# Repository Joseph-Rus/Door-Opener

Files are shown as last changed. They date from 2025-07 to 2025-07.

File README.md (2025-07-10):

# ESP32-C6 Telegram Door Control System

A secure, remote door control system using ESP32-C6 and Telegram Bot API. Control your door lock from anywhere in the world using your smartphone!

## 📋 Table of Contents
- [Features](#features)
- [Hardware Requirements](#hardware-requirements)
- [Software Requirements](#software-requirements)
- [Hardware Setup](#hardware-setup)
- [Software Setup](#software-setup)
- [Telegram Bot Setup](#telegram-bot-setup)
- [Arduino IDE Configuration](#arduino-ide-configuration)
- [Installation](#installation)
- [Usage](#usage)
- [Commands](#commands)
- [Wiring Diagram](#wiring-diagram)
- [3D Printed Parts](#3d-printed-parts)
- [Troubleshooting](#troubleshooting)
- [Security Features](#security-features)
- [Contributing](#contributing)
- [License](#license)

## ✨ Features

- **Remote Control**: Control your door from anywhere with internet connection
- **Secure Access**: Multi-user authorization with unique Telegram user IDs
- **Auto-lock**: Automatic door closure after 10 seconds
- **Real-time Notifications**: All authorized users get notified when door is opened
- **Status Monitoring**: Check door status and WiFi information
- **Power Management**: Optimized servo control to prevent overheating
- **Battery Support**: Built-in battery charging and monitoring
- **Fail-safe Design**: WiFi reconnection and error handling

## 🛠 Hardware Requirements

### Core Components
- **[Seeed Studio XIAO ESP32-C6](https://www.seeedstudio.com/Seeed-Studio-XIAO-ESP32C6-p-5884.html)** - Main microcontroller
- **[SONOFF 5V Relay Module](https://a.co/d/8S7qjCs)** - Controls power to servo
- **[Internal Battery - 3.7V 602030 LiPo](https://a.co/d/1w1Zyej)** - Internal backup power
- **[External Power Bank - Anker](https://a.co/d/4TOVGFS)** - External backup power
- **[2.4G WiFi Antenna](https://a.co/d/gJ13i0S)** - Enhanced WiFi range

### Servo Motors (Choose One)
- **Current Compatible**: [DS3235MG Servo](https://a.co/d/hh7hMv6) *(STL files available)*
- **Updated Model**: [High Torque Servo](https://a.co/d/5FDcMUa) *(STL files need updating)*

### Additional Components
- Jumper wires
- Breadboard or PCB
- **[3.7V 602030 LiPo Battery](https://a.co/d/1w1Zyej)** - Internal backup power
- **[Anker Power Bank](https://a.co/d/4TOVGFS)** - External backup power
- External antenna (optional for better range)

## 💻 Software Requirements

- **Arduino IDE** (version 1.8.13 or later)
- **ESP32 Board Package** (version 3.0.0 or later)
- **Required Libraries**:
  - UniversalTelegramBot
  - ArduinoJson (version 6.15.2 or later)
  - ESP32Servo
  - WiFiClientSecure

## 🔧 Hardware Setup

### ESP32-C6 Setup

The **Seeed Studio XIAO ESP32-C6** is a powerful, compact development board perfect for IoT projects:

#### Key Specifications
- **Processor**: Dual 32-bit RISC-V processors (160 MHz + 20 MHz)
- **Memory**: 512KB SRAM, 4MB Flash
- **Connectivity**: WiFi 6, Bluetooth 5.3, Zigbee, Thread
- **Size**: 21 x 17.8mm (ultra-compact)
- **Power**: Deep sleep mode (~15 µA)

#### Pin Configuration
```
GPIO Pins Used:
- GPIO 18: Relay control
- GPIO 17: Servo signal
- GPIO 15: Status LED
- GPIO 3:  WiFi RF switch control
- GPIO 14: Antenna selection
```

### Wiring Connections



```
ESP32-C6    →    Component
────────────────────────────
GPIO 18     →    Relay IN (Signal)
GPIO 17     →    Servo Signal (Orange/Yellow)
GPIO 15     →    LED + (through 220Ω resistor)
5V          →    Relay VCC
GND         →    Relay GND, Servo GND (Black/Brown), LED -

Relay Connections:
COM         →    5V Power Supply
NO          →    Servo VCC (Red)
```

### Power Management
The system uses intelligent power management:
1. **Relay Control**: Powers servo only when needed
2. **Battery Backup**: Automatic switching to battery power
3. **Deep Sleep**: Ultra-low power consumption when idle

## 📱 Telegram Bot Setup

### Step 1: Create Your Bot with BotFather

BotFather is Telegram's official bot creation tool. To get started, message @BotFather on Telegram to register your bot and receive its authentication token.

1. **Open Telegram** and search for `@BotFather`
2. **Start a conversation** and send `/newbot`
3. **Choose a name** for your bot (e.g., "My Door Control")
4. **Choose a username** ending with "bot" (e.g., "mydoor_control_bot")
5. **Save the token** - this is your `BOT_TOKEN`

### Step 2: Get Your User ID

In your Telegram account, search for "IDBot" or open this link t.me/myidbot on your smartphone. Start a conversation with that bot and type /getid. You will get a reply back with your user ID.

1. Search for `@myidbot` in Telegram
2. Start a conversation and send `/getid`
3. **Save your User ID** - this goes in `AUTHORIZED_USERS[]`

### Step 3: Configure Bot Commands (Optional)

You can set up bot commands by going to @BotFather > /mybots > Your_Bot_Name > Edit Bot > Edit Commands.

Add these commands:
```
start - Welcome message and help
open - Open door for 10 seconds
status - Check door status
help - Show available commands
```

## ⚙️ Arduino IDE Configuration

### Step 1: Install ESP32-C6 Board Support

To install the XIAO ESP32C6 board, add the board manager URL to the preferences of your Arduino IDE.

1. **Open Arduino IDE**
2. **Go to File → Preferences**
3. **Add this URL** to "Additional Board Manager URLs":
   ```
   https://espressif.github.io/arduino-esp32/package_esp32_index.json
   ```
4. **Open Tools → Board → Boards Manager**
5. **Search for "esp32"** and install version **3.0.0 or later**
6. **Select Board**: Tools → Board → ESP32 Arduino → **XIAO_ESP32C6**

### Step 2: Install Required Libraries

To establish communication with the Telegram bot, we'll be using the Universal Telegram Bot Library created by Brian Lough that provides an easy interface for Telegram Bot API.

Install these libraries via **Tools → Manage Libraries**:

1. **UniversalTelegramBot** by Brian Lough
2. **ArduinoJson** by Benoît Blanchon (version 6.15.2+)
3. **ESP32Servo** (included with ESP32 core)

## 📥 Installation

### Step 1: Clone Repository
```bash
git clone https://github.com/yourusername/esp32-telegram-door-control.git
cd esp32-telegram-door-control
```

### Step 2: Configure Settings
Open the Arduino sketch and update these variables:

```cpp
// WiFi credentials
const char* ssid = "your_wifi_name";
const char* password = "your_wifi_password";

// Telegram Bot settings
#define BOT_TOKEN "your_bot_token_from_botfather"

// Authorized users (add up to 3 user IDs)
const String AUTHORIZED_USERS[] = {"123456789"}; // Your Telegram user ID
const int NUM_AUTHORIZED_USERS = 1;
```

### Step 3: Upload Code
1. **Connect ESP32-C6** via USB-C cable
2. **Select correct port** in Tools → Port
3. **Upload the sketch**

### Step 4: Monitor Serial Output
- Open **Tools → Serial Monitor**
- Set baud rate to **115200**
- Verify WiFi connection and bot initialization

## 🎮 Usage

### First Time Setup
1. **Power on** the ESP32-C6
2. **Wait for WiFi connection** (check Serial Monitor)
3. **Open Telegram** and find your bot
4. **Send `/start`** to begin

### Daily Operation
- **`/open`** - Opens door for 10 seconds
- **`/status`** - Check current door state
- **`/help`** - Show all commands

### Notifications
- All authorized users receive notifications when:
  - Door is opened by someone
  - Door closes automatically
  - System status changes

## 📋 Commands

| Command | Description | Response |
|---|---|---|
| `/start` | Initialize bot and show welcome | Welcome message with available commands |
| `/open` | Open door for 10 seconds | "🔓 Door opened! Will close in 10 seconds" |
| `/status` | Check door and system status | Door state, WiFi IP, time remaining |
| `/help` | Show help information | Complete command list and instructions |

## 🔌 Wiring Diagram

```
    ESP32-C6 XIAO
    ┌─────────────┐
    │ ┌─┐     ┌─┐ │
    │ └─┘ USB └─┘ │
    │             │
    │  18 ────────┼─── Relay IN (Signal)
    │  17 ────────┼─── Servo Signal (Orange)
    │  15 ────────┼─── LED + (220Ω resistor)
    │  5V ────────┼─── Relay VCC
    │ GND ────────┼─── Relay GND, Servo GND (Black)
    └─────────────┘
           │
           │ 5V Power Supply
           ▼
    Relay Module        Servo Motor
    ┌─────────┐        ┌─────────┐
    │   VCC   │◄──5V───│         │
    │   GND   │◄──GND──│   GND   │ Black
    │   IN    │◄──18───│         │
    │   COM   │◄──5V───┤         │
    │   NO    │────────┤   VCC   │ Red
    │         │        │  Signal │ Orange ──► GPIO 17
    └─────────┘        └─────────┘

Power Flow:
5V Supply → Relay COM → Relay NO → Servo VCC
(Relay acts as power switch for servo)
```

## 🎯 3D Printed Parts

### Current STL Files
Compatible with **[DS3235MG Servo](https://a.co/d/hh7hMv6)**:
- Door mount bracket
- Servo housing
- Lock mechanism

### Updated Servo
**[High Torque Servo](https://a.co/d/5FDcMUa)** - *STL files need updating for this model*

> **Note**: If you choose the updated servo, you'll need to modify the STL files or design new mounts.

## 🔧 Troubleshooting

### WiFi Connection Issues
```cpp
// Check Serial Monitor for these messages:
"Connecting to WiFi..." - Normal startup
"WiFi connected!" - Success
"Failed to connect!" - Check credentials
```

### Bot Not Responding
1. **Verify bot token** in code
2. **Check user ID** in AUTHORIZED_USERS
3. **Confirm internet connection**
4. **Test with `/start` command**

### Servo Not Moving
1. **Check relay clicking sound**
2. **Verify servo connections**
3. **Test servo power supply**
4. **Ensure relay is working**

### Authorization Failures
```
"❌ Unauthorized access" - User ID not in authorized list
```

### ESP32-C6 Specific Issues

When you encounter problems with ESP32C6, you can try to put XIAO into BootLoader mode, which can solve most of the problems of unrecognized devices and failed uploads.

**BootLoader Mode**:
1. Press and hold **BOOT** button
2. Connect USB cable while holding BOOT
3. Release BOOT button
4. Upload code

## 🔒 Security Features

### Multi-User Authorization
- **User ID Verification**: Only authorized Telegram user IDs can control the door
- **Session Management**: Each command is verified before execution
- **Audit Trail**: All access attempts are logged to Serial Monitor

### Network Security
- **WPA2/WPA3 WiFi**: Secure wireless connection
- **HTTPS**: All Telegram API calls use encrypted connection
- **Token Protection**: Bot token should be kept secret

### Physical Security
- **Auto-lock**: Door automatically closes after 10 seconds
- **Power Failure Safe**: Battery backup maintains security
- **Manual Override**: Physical reset button available

## 🔋 Power Management

### Battery Configuration
The XIAO ESP32C6 features a built-in power management chip, allowing it to be powered independently by a battery or to charge the battery through its USB port. The recommended battery is a **[3.7V 602030 LiPo battery](https://a.co/d/1w1Zyej)** which fits perfectly with the XIAO form factor.

When connecting the battery to your XIAO, carefully distinguish between the positive and negative terminals. The negative electrode pad should be located on the left side near the silk screen marking "D8," while the positive electrode pad should be located on the right side near the silk screen marking "D5."

```cpp
// Battery voltage monitoring
uint32_t Vbatt = 0;
for(int i = 0; i < 16; i++) {
    Vbatt += analogReadMilliVolts(A0);
}
float Vbattf = 2 * Vbatt / 16 / 1000.0; // Convert to volts
```

### Power Modes
- **Active Mode**: ~30mA (door operations)
- **Light Sleep**: ~2.5mA (waiting for commands)
- **Deep Sleep**: ~15µA (extended idle periods)

## 🤝 Contributing

We welcome contributions! Please follow these steps:

1. **Fork the repository**
2. **Create a feature branch**: `git checkout -b feature/amazing-feature`
3. **Commit changes**: `git commit -m 'Add amazing feature'`
4. **Push to branch**: `git push origin feature/amazing-feature`
5. **Open a Pull Request**

### Areas for Contribution
- STL file updates for new servo motor
- Additional security features
- Power optimization
- Mobile app interface
- Documentation improvements

## 📚 Additional Resources

### Documentation Links
- **[ESP32-C6 Getting Started Guide](https://wiki.seeedstudio.com/xiao_esp32c6_getting_started/)**
- **[Telegram Bot API Documentation](https://core.telegram.org/bots/api)**
- **[Universal Arduino Telegram Bot Library](https://github.com/witnessmenow/Universal-Arduino-Telegram-Bot)**
- **[ESP32 Arduino Core Documentation](https://docs.espressif.com/projects/arduino-esp32/en/latest/)**

### Hardware Datasheets
- [ESP32-C6 Technical Reference](https://files.seeedstudio.com/wiki/SeeedStudio-XIAO-ESP32C6/res/esp32-c6_datasheet_en.pdf)

## 📄 License

This project is licensed under the MIT License - see the [LICENSE](LICENSE) file for details.

## 🙏 Acknowledgments

- **Espressif Systems** for the ESP32-C6 chip
- **Seeed Studio** for the XIAO ESP32-C6 board
- **Brian Lough** for the Universal Telegram Bot Library
- **Telegram Team** for the excellent Bot API
- **Arduino Community** for the development environment

---

## 🚀 Quick Start Summary

1. **Hardware**: Connect relay to GPIO18, servo to GPIO17
2. **Software**: Install Arduino IDE + ESP32 board + libraries
3. **Telegram**: Create bot with @BotFather, get token and user ID
4. **Code**: Update WiFi credentials, bot token, and user ID
5. **Upload**: Flash code to ESP32-C6
6. **Test**: Send `/start` to your bot!

**Happy Building! 🏠🔐**

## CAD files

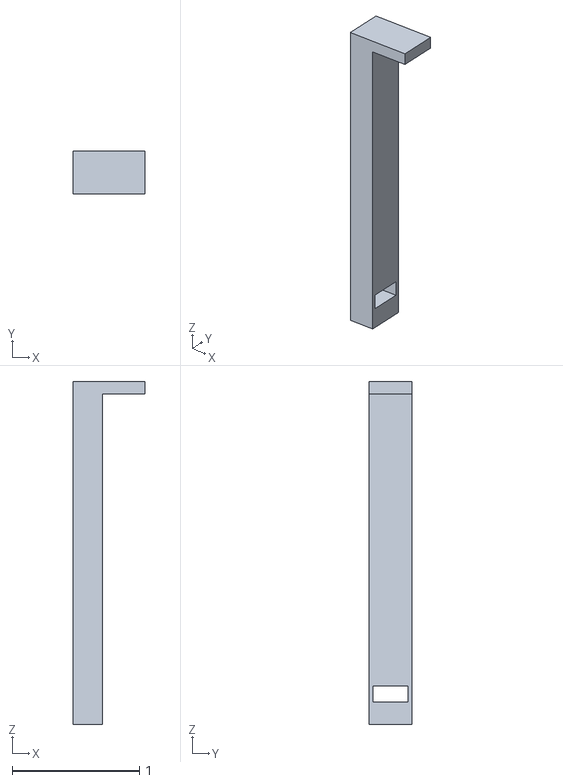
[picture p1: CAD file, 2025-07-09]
bar_to_hold_servo.stl
0.564 x 0.34 x 2.70

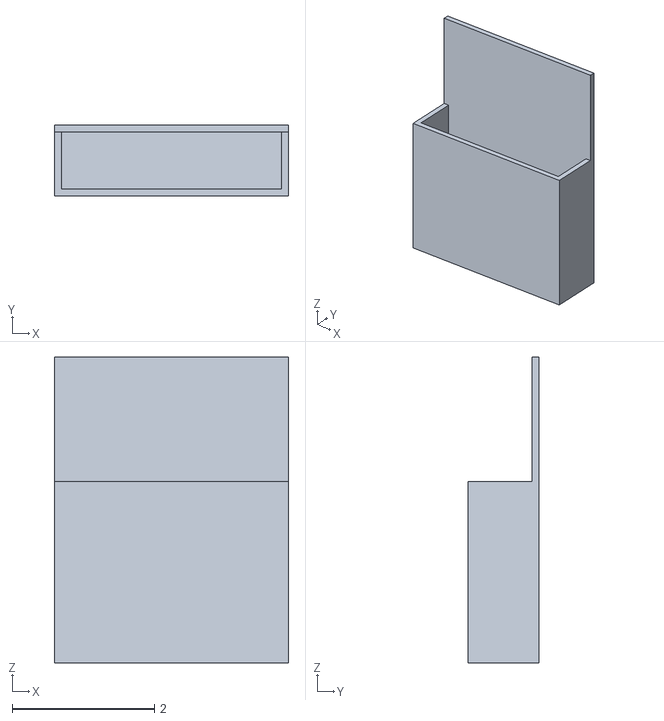
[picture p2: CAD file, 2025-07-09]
batteryholder.stl
3.30 x 1.00 x 4.31

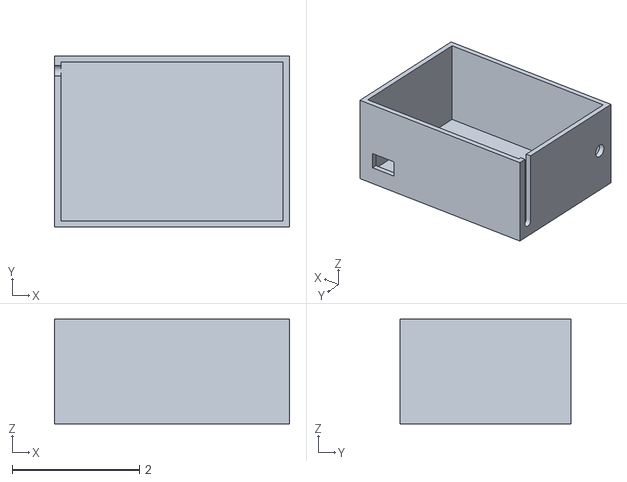
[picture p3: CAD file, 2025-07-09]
case.stl
3.70 x 2.70 x 1.65

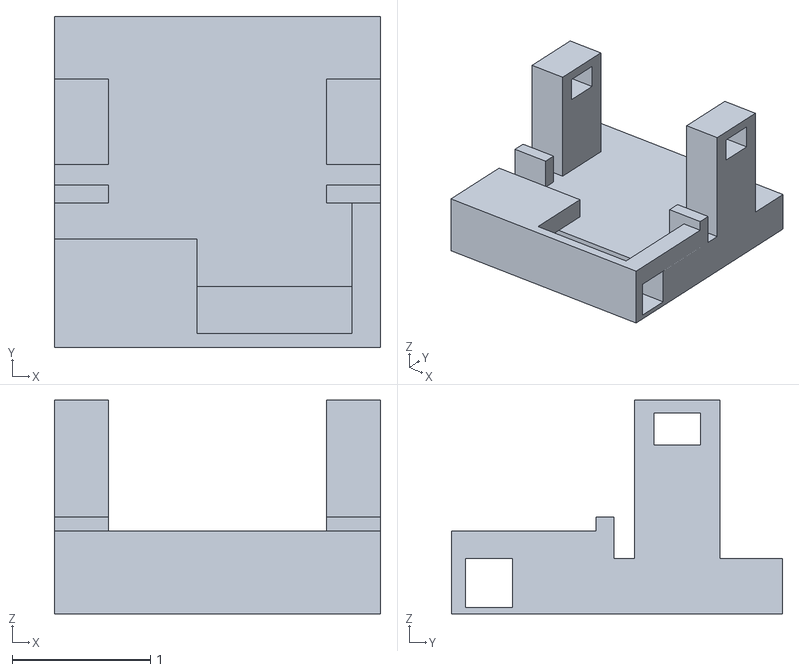
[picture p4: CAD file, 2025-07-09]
servo_holder.stl
2.36 x 2.39 x 1.54

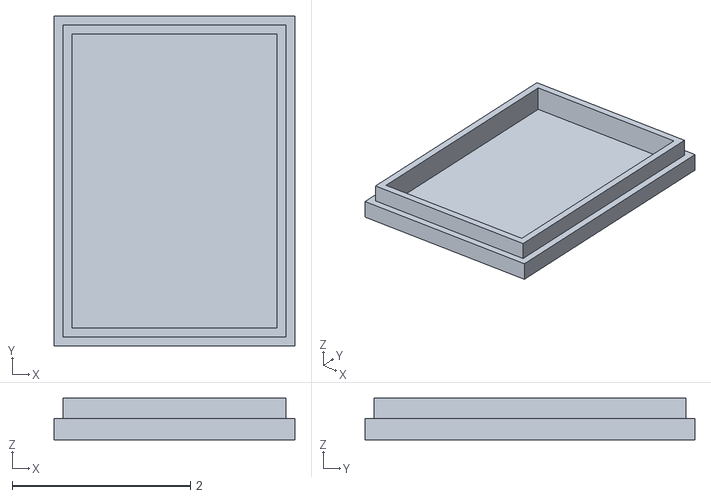
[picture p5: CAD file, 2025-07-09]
lid.stl
2.70 x 3.70 x 0.47

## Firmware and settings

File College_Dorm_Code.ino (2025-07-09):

#include <WiFi.h>
#include <WiFiClientSecure.h>
#include <UniversalTelegramBot.h>
#include <ArduinoJson.h>
#include <ESP32Servo.h>

const char* ssid = "wifi_name";
const char* password = "wifi_password";

// Telegram Bot Token - GET THIS FROM BOTFATHER
#define BOT_TOKEN "token_from_bot_father"

// Authorized users - Add your 3 user IDs here
// Authorized users - Add your 3 user IDs here
const String AUTHORIZED_USERS[] = {"users_id"}; // Replace with actual user IDs

const int NUM_AUTHORIZED_USERS = 1;

WiFiClientSecure client;
UniversalTelegramBot bot(BOT_TOKEN, client);

// Hardware pins
const int RELAY_PIN = 18;     // GPIO18 controls relay 
const int SERVO_PIN = 17;     // GPIO16 controls servo
const int LED_PIN = 15;       // User LED

// Servo setup
Servo ds3235;
bool servoAttached = false;
bool relayState = false;

// Servo positions
const int closedPosition = 0;
const int openPosition = 270;    // Full 270 degree rotation

// Timing for auto-close
bool servoIsOpen = false;
unsigned long servoOpenTime = 0;
const unsigned long servoOpenDuration = 10000; // 10 seconds

// Timing for Telegram
unsigned long lastTimeBotRan;
const int botRequestDelay = 1000; // Check for messages every 1 second

// Security function 
bool isAuthorizedUser(String chat_id) {
  for (int i = 0; i < NUM_AUTHORIZED_USERS; i++) {
    if (chat_id == AUTHORIZED_USERS[i]) {
      return true;
    }
  }
  return false;
}

void setup() {
  Serial.begin(115200);
  delay(1000);

  Serial.println("=================================");
  Serial.println("Multi-User Telegram Servo Control");
  Serial.println("=================================");

  // Initialize hardware
  pinMode(RELAY_PIN, OUTPUT);
  pinMode(LED_PIN, OUTPUT);
  pinMode(SERVO_PIN, OUTPUT);

  // Start with door locked
  digitalWrite(RELAY_PIN, LOW);
  digitalWrite(LED_PIN, LOW);

  // Connect to WiFi
  WiFi.mode(WIFI_STA);
  WiFi.disconnect();
  delay(100);
  
  WiFi.begin(ssid, password);
  Serial.print("Connecting to WiFi");

  int attempts = 0;
  while (WiFi.status() != WL_CONNECTED && attempts < 20) {
    delay(500);
    Serial.print(".");
    attempts++;
  }

  if (WiFi.status() != WL_CONNECTED) {
    Serial.println("\nFailed to connect to WiFi!");
    Serial.println("Restarting in 5 seconds...");
    delay(5000);
    ESP.restart();
  }

  Serial.println("\nWiFi connected!");
  Serial.print("IP address: ");
  Serial.println(WiFi.localIP());
  Serial.print("Signal strength (RSSI): ");
  Serial.print(WiFi.RSSI());
  Serial.println(" dBm");

  // Configure secure client
  client.setCACert(TELEGRAM_CERTIFICATE_ROOT);

  // Test bot connection
  Serial.print("Retrieving bot name: ");
  if (bot.getMe()) {
    Serial.println("✓ Telegram bot connected successfully!");
  } else {
    Serial.println("✗ Failed to connect to Telegram bot");
    Serial.println("Check your BOT_TOKEN and internet connection");
  }

  Serial.println("=================================");
  Serial.println("Bot Ready! Available commands:");
  Serial.println("/start - Welcome message");
  Serial.println("/open  - Open servo for 10 seconds");
  Serial.println("/status - Check servo state");
  Serial.println("/help  - Show help");
  Serial.println("=================================");
}

void loop() {
  // Check for new Telegram messages
  if (millis() > lastTimeBotRan + botRequestDelay) {
    int numNewMessages = bot.getUpdates(bot.last_message_received + 1);
    
    while (numNewMessages) {
      handleNewMessages(numNewMessages);
      numNewMessages = bot.getUpdates(bot.last_message_received + 1);
    }
    lastTimeBotRan = millis();
  }

  // Auto-close door
  if (servoIsOpen && millis() - servoOpenTime >= servoOpenDuration) {
    closeDoor();
  }

  delay(10);
}

void handleNewMessages(int numNewMessages) {
  for (int i = 0; i < numNewMessages; i++) {
    String chat_id = String(bot.messages[i].chat_id);
    String text = bot.messages[i].text;
    String from_name = bot.messages[i].from_name;
    
    Serial.println("Message from " + from_name + " (ID: " + chat_id + "): " + text);
    
    // Security check - only allow authorized users
    if (!isAuthorizedUser(chat_id)) {
      bot.sendMessage(chat_id, "❌ Unauthorized access. Contact admin for permission.", "");
      Serial.println("Unauthorized access attempt from: " + from_name + " (ID: " + chat_id + ")");
      continue;
    }
    
    if (text == "/start") {
      String welcome = "🤖 *Secure Door Control Bot*\n\n";
      welcome += "Welcome " + from_name + "!\n\n";
      welcome += "Available commands:\n";
      welcome += "/open - Open door for 10 seconds\n";
      welcome += "/status - Check door status\n";
      welcome += "/help - Show this message";
      bot.sendMessage(chat_id, welcome, "Markdown");
    }
    
    else if (text == "/open") {
      if (!servoIsOpen) {
        openDoor();
        bot.sendMessage(chat_id, "🔓 Door opened by " + from_name + "! Will close automatically in 10 seconds.", "");
        
        // Notify other users
        notifyOtherUsers(chat_id, "🔓 Door opened by " + from_name);
      } else {
        unsigned long timeLeft = servoOpenDuration - (millis() - servoOpenTime);
        bot.sendMessage(chat_id, "⚠️ Door is already open! Closing in " + String(timeLeft/1000) + " seconds.", "");
      }
    }
    
    else if (text == "/status") {
      String status = "📊 *Door Status*\n\n";
      if (servoIsOpen) {
        unsigned long timeLeft = servoOpenDuration - (millis() - servoOpenTime);
        status += "🔓 Status: OPEN\n";
        status += "⏱️ Time left: " + String(timeLeft/1000) + " seconds";
      } else {
        status += "🔒 Status: CLOSED";
      }
      status += "\n🌐 WiFi: " + WiFi.localIP().toString();
      bot.sendMessage(chat_id, status, "Markdown");
    }
    
    else if (text == "/help") {
      String help = "🤖 *Secure Door Control Help*\n\n";
      help += "This bot controls a door lock remotely.\n\n";
      help += "Commands:\n";
      help += "/open - Opens the door for 10 seconds (270° rotation)\n";
      help += "/status - Shows current door state\n";
      help += "/help - Shows this help message\n\n";
      help += "The door will automatically close after 10 seconds.\n";
      help += "All authorized users will be notified when someone opens the door.";
      bot.sendMessage(chat_id, help, "Markdown");
    }
    
    else {
      bot.sendMessage(chat_id, "❌ Unknown command. Send /help for available commands.", "");
    }
  }
}

void notifyOtherUsers(String excludeChat, String message) {
  for (int i = 0; i < NUM_AUTHORIZED_USERS; i++) {
    if (AUTHORIZED_USERS[i] != excludeChat && AUTHORIZED_USERS[i] != "") {
      bot.sendMessage(AUTHORIZED_USERS[i], message, "");
    }
  }
}

// =======================================================
// == POWER MANAGEMENT FUNCTIONS WITH 270° ROTATION ==
// =======================================================

void openDoor() {
  Serial.println(">>> OPENING DOOR <<<");
  digitalWrite(LED_PIN, LOW); // Turn off LED to save a little power

  // 1. Attach the servo first, before the main power draw from the relay.
  if (!servoAttached) {
    ds3235.attach(SERVO_PIN);
    servoAttached = true;
    delay(500); // Wait for servo to initialize
  }

  // 2. Now, turn on the relay. This likely powers the servo's motor.
  digitalWrite(RELAY_PIN, HIGH);
  delay(500); // Give the power supply a moment to stabilize after the relay clicks on.

  Serial.println("Moving servo to open position (270°)...");
  
  // 3. Move the servo gradually to the open position (270°) to reduce current spikes.
  for (int pos = closedPosition; pos <= openPosition; pos += 5) { // Move in 5-degree increments
    ds3235.write(pos);
    delay(30); // Slower movement for the larger rotation
  }
  ds3235.write(openPosition); // Ensure it reaches the final position (270°)

  // 4. Set state for auto-close logic
  servoIsOpen = true;
  servoOpenTime = millis();

  digitalWrite(LED_PIN, HIGH); // Turn LED back on
  Serial.println("Door opened to 270°!");
}

void closeDoor() {
  Serial.println(">>> CLOSING DOOR <<<");

  if (servoAttached) {
    Serial.println("Moving servo to closed position (0°)...");
    
    // 1. Gradually move the servo back to the closed position.
    for (int pos = openPosition; pos >= closedPosition; pos -= 5) { // Move in 5-degree decrements
      ds3235.write(pos);
      delay(30); // Slower movement for the larger rotation
    }
    ds3235.write(closedPosition); // Ensure it's fully closed (0°)
    delay(500); // Let servo settle

    // 2. Detach the servo to stop it from drawing power to hold its position.
    ds3235.detach();
    servoAttached = false;
    delay(200); // Brief pause before cutting power
  }

  // 3. Cut power by turning off the relay.
  digitalWrite(RELAY_PIN, LOW);
  digitalWrite(LED_PIN, LOW);

  servoIsOpen = false;
  Serial.println("Door closed and locked.");
  
  // Notify all users that door closed
  notifyOtherUsers("", "🔒 Door closed automatically");
}
